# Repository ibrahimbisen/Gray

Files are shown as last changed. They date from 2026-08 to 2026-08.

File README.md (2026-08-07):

# Gray

**A 12-DOF quadruped robot.** Two students designed it, printed it, and built it.
The software teaches it to walk with reinforcement learning.

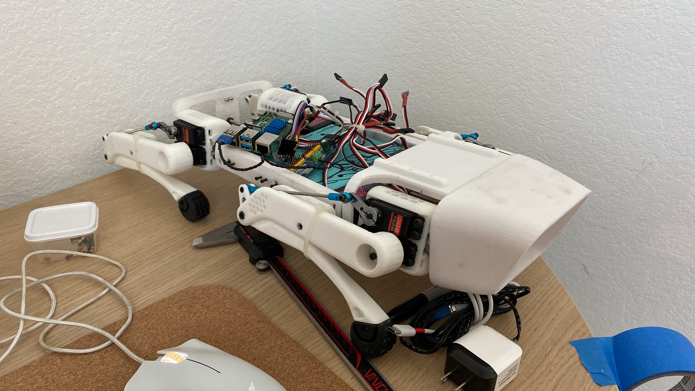
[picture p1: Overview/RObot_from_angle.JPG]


The robot is built. The parts are apart on a shelf. The work now is in simulation:
teach it to walk, teach it to stand up, then put the policy on the real machine.

---

## What it can do today

Every number below is measured in simulation, on 64 robots, over 25 seconds.
Nothing here is an estimate.

| | measured | it must reach |
|---|---|---|
| Walks forward | 6.7 m | 5.0 m |
| Top speed | 0.72 m/s — 2.6 km/h | — |
| Holds a straight line | 4.5° off | 7° |
| Turns on the spot | within 0.23 rad/s | 0.45 rad/s |
| Stays upright | 100 of 100 attempts | 90 |
| Climbs a 10° slope | 98 of 100 stay up | — |
| **Criteria passed** | **10 of 11** | 11 |

The one criterion left is the sideways walk. It misses by 3 mm/s.

Two policies made this table. The flat policy holds the line and the speed. A second
policy, trained on hills, does the climb. Hills and a straight walk pull against each
other: train on slopes and the line costs about 1.7° more. One policy for both is the
next decision, not a finished result.

---

## The robot

| | |
|---|---|
| Joints | 12 — three per leg |
| Servos | 12 × DS3218MG, 1.96 N·m, 270° |
| Mass | 3.1 kg |
| Sensors | 3 IMUs on the trunk, a potentiometer on every joint |
| Computer | Raspberry Pi, with an external ADC for the potentiometers |

**Three hardware facts change how the software must work.**

- The knee is a pushrod linkage. The servo angle is **not** the joint angle. A linear
  potentiometer on the rod measures the true knee angle.
- The servos take PWM at 50 Hz. That is the control ceiling. Feedback changes what the
  robot can sense, not how fast it can move.
- Only four servos sit in the body. Eight sit in the hip modules. The thigh and the calf
  hold no servo at all. This sets how heavy a leg is to swing.

---

## How to run it

Start two processes, in two terminals. Each one continues if you close the other.

```
python run.py              the training centre, at http://127.0.0.1:8000
python run.py --runner     works through the queue, unattended
```

Put jobs in the queue from the dashboard. The runner does them, one at a time.
Each job is **train**, then **verify**, then **film**.

Two training processes on one graphics card stop each other. So the runner takes one
job at a time, and that rule is structural rather than something to remember.

> ### Caution
> **Do not open a simulator window while a run trains.** A second process on the same
> card once stopped the machine and lost the run. This includes `Playground/pilot.py`,
> `scripts/drive.py`, and `find_stance.py --render`.
> The dashboard is safe. It uses the CPU only.

### Other commands

| | |
|---|---|
| `python run.py --check` | what the dashboard can see, then exit |
| `python scripts/train.py Gray-Walk --iterations 3000` | train one policy by hand |
| `python scripts/verify.py Gray-Walk` | score a policy against its criteria |
| `python scripts/scale_test.py` | how many robots this card can hold |
| `python Playground/pilot.py --run <run> --playground` | drive a trained policy yourself |
| `python tools/prepare_model.py "sim/URDF and Meshes V2"` | rebuild the model from CAD |

The three tasks are `Gray-Stand`, `Gray-Push` and `Gray-Walk`.

---

## Where to read more

| | |
|---|---|
| [PLAN.md](PLAN.md) | the stages, and the number each stage must reach |
| [RULES.md](RULES.md) | the decisions that hold across the project, and why |
| [CLAUDE.md](CLAUDE.md) | the hardware facts that do not change |
| [docs/REWARDS.md](docs/REWARDS.md) | what each reward term pays for |
| [Playground/README.md](Playground/README.md) | how to drive a policy by hand |

The dashboard holds more than these files do. It reads the live code, so it cannot
disagree with what the robot actually trained on.

---

## The machine

**The CAD model, and the URDF the simulation reads.**

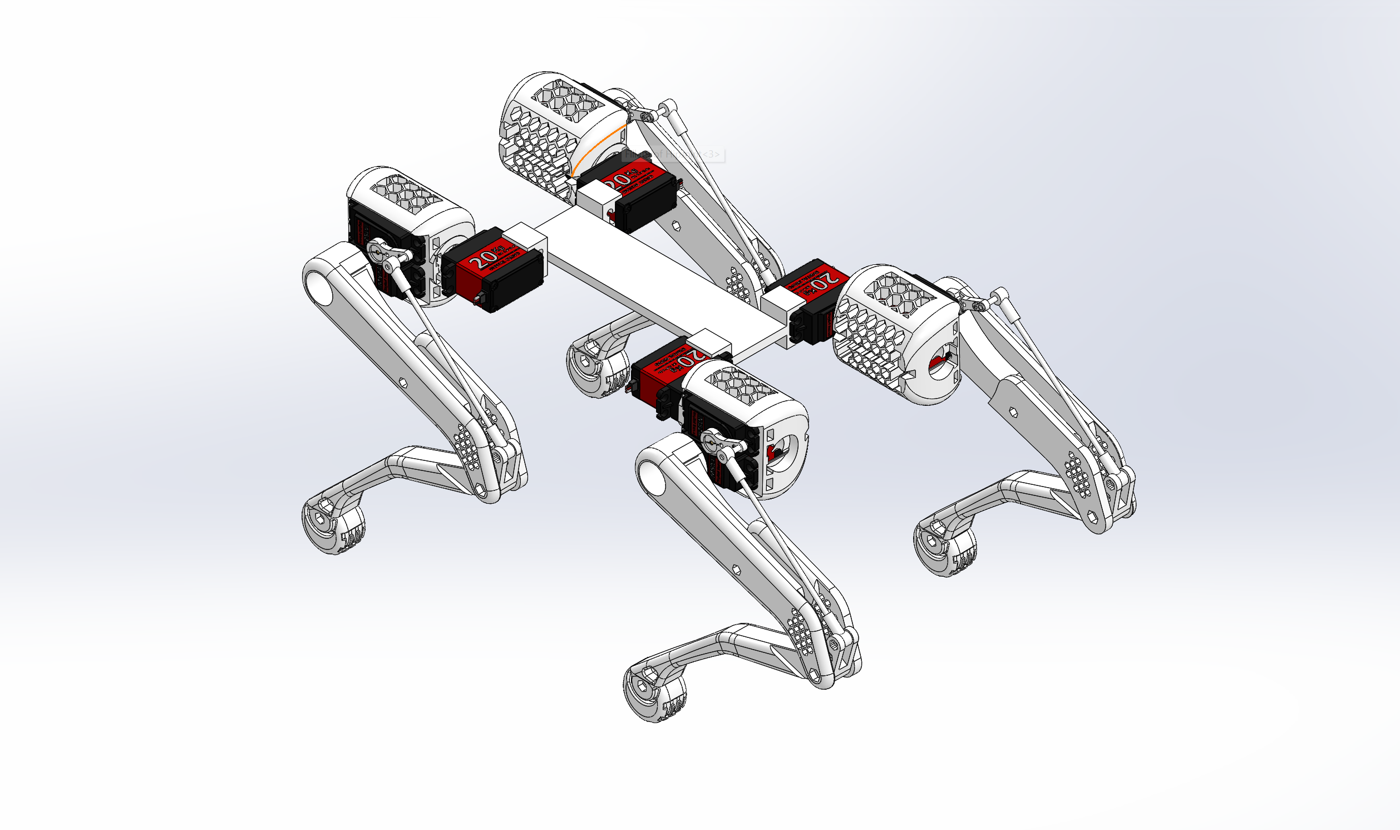
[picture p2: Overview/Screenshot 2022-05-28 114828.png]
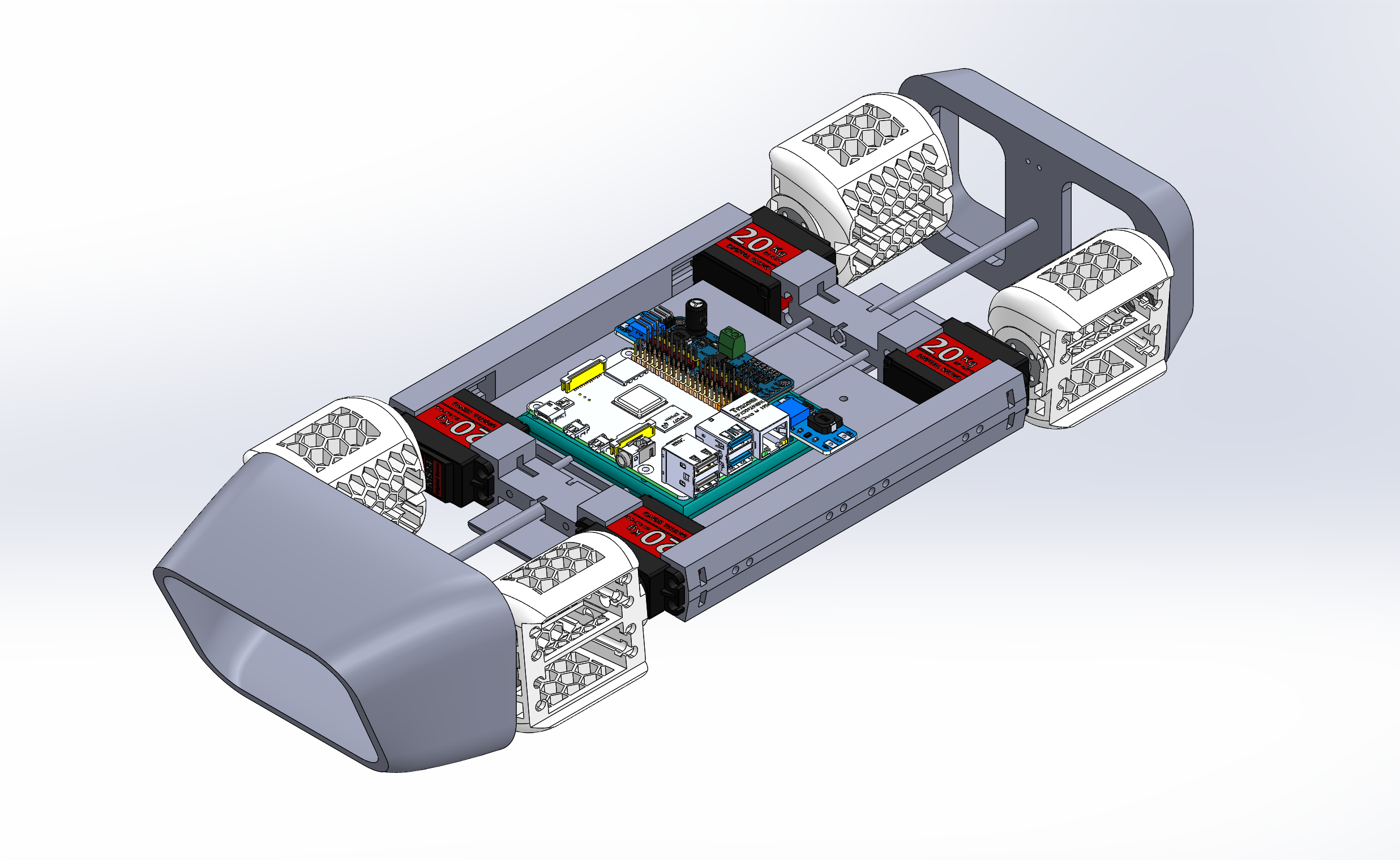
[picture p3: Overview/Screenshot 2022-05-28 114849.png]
 

**The build.** The controller, the legs, and the body with its electronics.

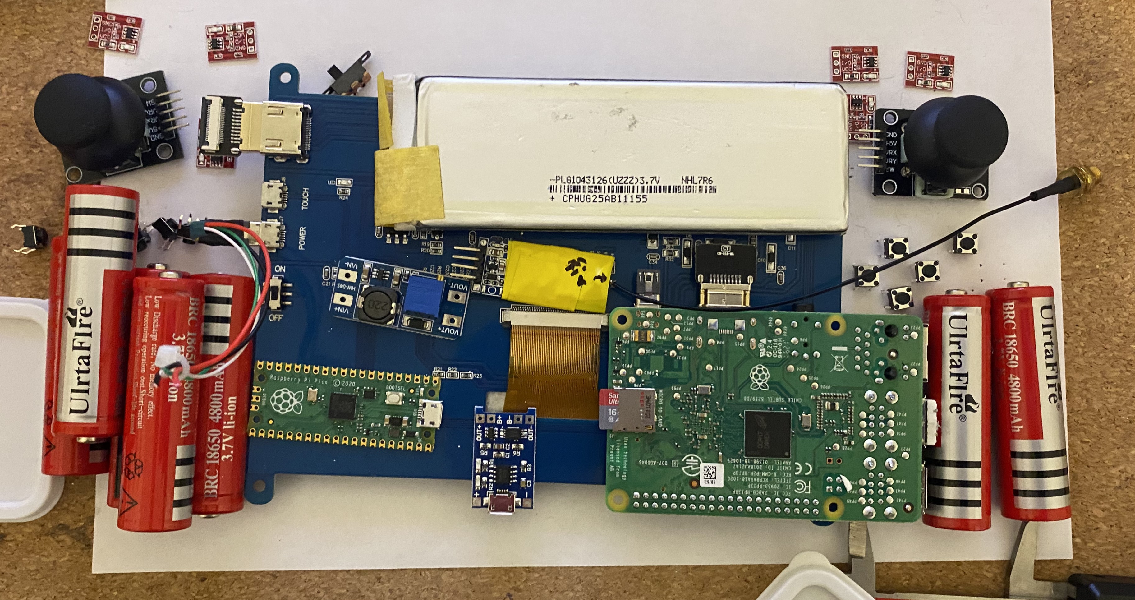
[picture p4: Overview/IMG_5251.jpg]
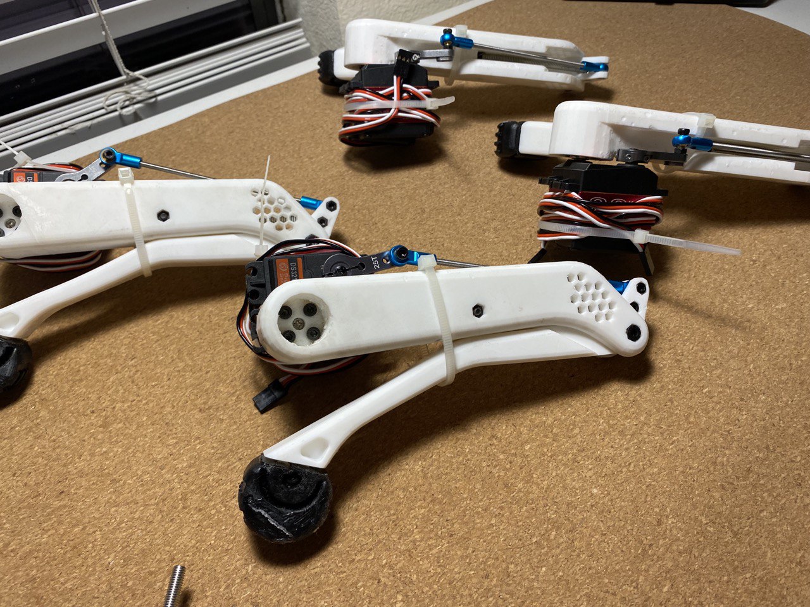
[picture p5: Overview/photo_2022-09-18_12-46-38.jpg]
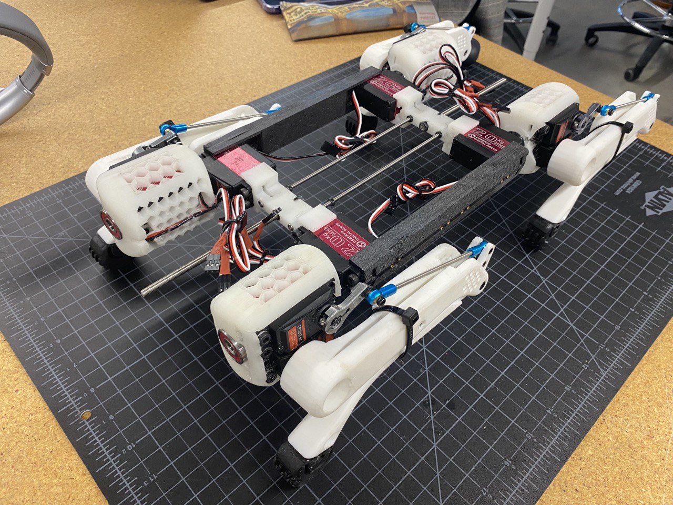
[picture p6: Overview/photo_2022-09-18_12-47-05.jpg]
  

**The first walk tests on the real robot.**



**In simulation.** Run 182, the most recent walk run, at three points in its training.
Each clip is 8 seconds. A pinned command drives the robot forward at 0.49 m/s, which is
70 percent of its 0.7 m/s top command. The camera trails the robot, so the ground shows
the distance covered.

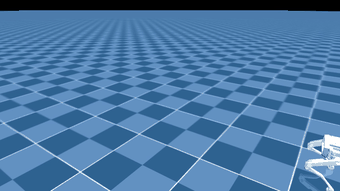
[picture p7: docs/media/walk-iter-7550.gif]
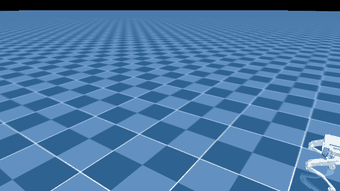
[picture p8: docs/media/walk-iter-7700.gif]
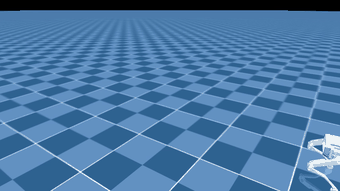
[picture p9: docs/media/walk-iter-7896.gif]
  

Run 182 tests a penalty that holds the hips near their home angle. It did not pass the
walk criteria, so these clips show the newest policy, not the best one. Over 8 robots it
covers 2.2 to 3.3 m in the 8 seconds, and none of them fall. The table at the top of this
page comes from two other policies.

**The earlier attempt**, at three points in its training. This software stack used a bad
CAD export, and the git tag `archive/attempt-1` holds it. The robot in these clips is the
old model.

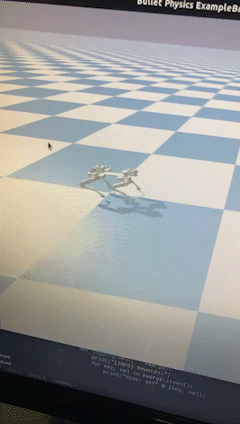
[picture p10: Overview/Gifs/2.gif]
  

---

## Contributors

- Ibrahim Eren Bisen
- Emin Alp Arslan

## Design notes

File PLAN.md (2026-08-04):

# PLAN.md — stage 2, train

Agreed 3 Aug 2026. This replaces the nine-subsection structure the dashboard
used to show.

**Where we are: 1.1.2 — and 1.2 has already happened.**

**Changed 3 Aug 2026, after 1.1.1.** 1.2 was going to come after 1.1, on the
grounds that you cannot tell whether a wider box broke something if the narrow
box was already broken. That was right while the plan was "tune the reward now,
widen later". It stopped being right the moment the decision was made to widen
*and* to add height, pitch and roll — because both throw every trained policy
away, so tuning the reward first would have meant tuning it twice.

So 1.2.1 to 1.2.3 are done, and **1.1 and 1.2.4 are now the same work**: the
rounds below tune the reward directly on the final box rather than on a box that
was about to be replaced. What that costs is the thing 1.2 was ordered after 1.1
to avoid — a harder debugging job if drift is still wrong. What it buys is not
paying for 25 hours of GPU twice.

---

## The shape

One pattern, applied twice.

    train it  ->  harden it  ->  measure it

Locomotion first, then getting up. Then join them. Then the sensors, twice: once
to keep what you had, once to use them.

**Every step ends on a number, not a date.** Nobody knows how long a reward
takes to get right — that is what the gates are for.

**Two things get tuned and they fight each other.** The REWARD says what good
means. The RANGE says where it has to be good. Widening the range makes the same
reward harder to satisfy, so they cannot be finished one after the other. That
is why the range stays pinned at its narrowest until 1.1 passes: you cannot tell
whether a wider range broke something if the narrow one was already broken.

---

## 1. Locomotion

### 1.1 Make it walk

- **1.1.1** Fix `wandering` to measure the line it was sent along — **done, 3 Aug**
- **1.1.2** Round 0 — noise floor. 3 seeds, one config
- **1.1.3** Round 1 — straightness factorial. 8 runs
- **1.1.4** Round 2 — speed terms. 4 runs
- **1.1.5** Round 3 — the winner, long, on unseen seeds. 3 runs
- **1.1.6** Add handover-shaped resets to R1's mix — *preparation for step 3*

> **Gate:** all six R1 criteria pass. Currently 4 of 6 — sideways drift is 21×
> its bar and speed tracking is 1.4× its bar.

Round 0 looks like the least and matters the most. Three identical configs on
three seeds; whatever they disagree by is the noise floor, and every later
difference has to beat it before it means anything.

### 1.2 The whole command box

- **1.2.1** Fix `_going_straight` to gate on `abs(vx)` — **done, 3 Aug**
- **1.2.2** Widen `WALK_SPEED` through zero to negative — **done, 3 Aug.**
  `(-0.35, 0.35)`. `WALK_SIDE` to `±0.20`, `WALK_TURN` to `±1.00`
- **1.2.3** Let `vy` be sampled without `vx` — **done, 3 Aug**
- **1.2.4** Retune — **this is now what 1.1's rounds do**
- **1.2.5** Add height, pitch and roll to the command — **done, 3 Aug.**
  Observation 45 → 48. Ranges measured, not chosen: height 0.15–0.25 m, pitch
  15° up to 8° down, roll ±20°, all inside where `find_stance` says the legs
  run out
- **1.2.6** Make the backward bar bite. **Not done.** `verify.py` carries
  `test_speed_back: -0.35` and reads it nowhere — the walk test still runs one
  pass, forward. Until it runs two and scores the worse, a run can be marked
  passed on forward alone. `drive.py --cases "-0.35,0,0"` measures it by hand
  in the meantime

> **A third thing was found here, and it was not in the plan.** mjlab's
> `rel_forward_envs` — set to 0.8 — did `.abs().clamp(min=0.3)` on the forward
> speed. On the old box that meant four attempts in five were forced to at least
> 0.3 m/s, three quarters of them landing exactly on it: the policy never trained
> across 0.15–0.35 at all. It trained at one speed. That is a live candidate for
> why speed tracking has been failing at 0.071 against a 0.05 bar. The `abs()`
> would also have flipped every backward command positive, so widening the range
> would have bought nothing. Replaced by `gray/tasks/walk_command.py`.

> **Gate:** the same six criteria, across the full range.

Measured on run #25: backward walked 0.00 m in 8 seconds, and pure sideways
walked 3 cm. Neither was ever sampled — `WALK_SPEED` is `(0.15, 0.35)`, so `vx`
is never zero and never negative. Four library rows filed as commands are not.

**1.2.1 must come first.** Widening the range without it trains backward walking
with no straightness penalty at all.

### 1.2b Steer it toward a crawl, not a trot — **owner's call, 4 Aug 2026**

The policy currently trots: diagonal pairs, front-right with back-left, lifting
together. Confirmed by watching run 34's films.

A trot is two feet down and the body falling between steps, caught by the servos
twice per stride. A crawl is one foot up and three always planted, so the weight
never leaves the triangle they make and nothing has to be caught.

In simulation the trot is fine — better, even. On the real robot it asks
DS3218MGs at 50 Hz, with backlash nobody has measured, to arrest a falling 3.1 kg
body twice a stride. **The owner's judgement is that they will not.** He built the
robot; that call is his and it is the right way round to be wrong.

So this is a sim-to-real decision made *before* the evidence rather than after,
which is unusual here and deliberate: finding out in stage 3.3 means every policy
trained until then is trained toward a gait the hardware cannot run.

**Not yet designed.** The honest options are a duty-factor term paying for three
feet down, a contact-schedule reward, or simply a much lower top speed — a trot
is partly what you get for asking for speed. Which one, and what it costs the
other bars, is the first thing to work out. It is NOT a weight change to
`stepping`: that term is already earning the maximum a trot can give it.

---

### 1.3 Turn the dials up

- **1.3.1** Widen what is already on — friction, mass, centre of mass, servo
  gains, joint friction
- **1.3.2** Terrain — slopes first, then uneven ground
- **1.3.3** Payload — to +2 kg, off-centre
- **1.3.4** Degraded hardware — weak servo, dead servo, low battery

> **Gate:** the same six criteria, dials at full.

The dials are not off. Foot friction is randomised 0.4 to 1.2 on every attempt
right now, along with ±20% mass, ±15 mm centre of mass and ±30% servo stiffness.
This step turns them up, it does not switch them on.

None of it is a new skill. The policy never sees the word gravel — it sees the
same 45 numbers in a different pattern. This is also where sim-to-real
robustness comes from: a policy that survives the range survives the real value,
which is the correct answer to three numbers nobody can measure yet.

### 1.4 Measure

- **1.4.1** Top speed, and the speed ladder
- **1.4.2** Acceleration, sustained run
- **1.4.3** Smoothness, read off the trained policy

> **No gate.** Numbers written down, nothing trained.

"Find top speed" has no reward term. You raise the command until it fails and
write down where. The trained half of smoothness — `twitching`, `rocking`,
`shaking`, `joint_shock`, `landing_speed` — is already ramping in during 1.1.

---

## 2. Getting up

### 2.1 Make it stand up

- **2.1.1** Write the recover task — start poses, reward, terminations
- **2.1.2** Reward it for **ending where R1 starts** — stable, at ride height,
  low joint velocity — *preparation for step 3*
- **2.1.3** Train it

> **Gate:** up from 9 of 10 random ground poses, in under 3 s.

The one group that genuinely needs its own policy file. There is no commanded
velocity to track when the robot is on its back, so `track_speed`, `stepping`,
`dragging` and `wandering` are all meaningless.

### 2.2 Turn the dials up

- **2.2.1** The same dials as 1.3, applied to R2

> **Gate:** still 9 of 10, dials at full.

### 2.3 Measure

- **2.3.1** Time to stand, per start pose

> **No gate.**

---

## 3. Join them up

- **3.1** The switch rule — hysteresis and a settle time, so control cannot
  chatter at the boundary
- **3.2** The test — 100 drops: R2 stands it up, hands over, R1 walks 5 m

> **Gate:** 100 handovers with no stall and no fall-loop.

**The failure this prevents.** R2 finishes and says "upright, take it." R1
receives a robot mid-wobble, with joint velocities and a trunk height it has
never seen, because R1's resets always start it clean:

    nudge_base:  x, y ±0.01 m,  yaw ±0.1 rad,  velocity_range {}
    joint reset: velocity ±0.05 rad/s

That is a robot standing still. R1 has trained on nothing else. Hand it an
out-of-distribution state and it falls; R2 picks it up, hands over, it falls
again. No runtime rule fixes that loop.

**Which is why 1.1.6 and 2.1.2 exist.** The preparation happens during training,
in the two steps above. Only the switch rule and the test are genuinely here. Skip
the preparation and this step is where you find out.

---

## 4. Sensors — keep what you had

- **4.1** Fit them. CAD positions needed for the three where the mounting is in
  the maths
- **4.2** Model each one in the simulator, including how it fails
- **4.3** Warm-start — grow the network, copy the old weights across, initialise
  the new input columns to **zero** so day one behaves identically to the best
  policy
- **4.4** Retrain R1 and R2 from that warm start

> **Gate:** every bar that passed before still passes, with 95 inputs.

Ten sensors decided; seven add inputs. 45 → 95 numbers, which is why they go in
as one batch: each one alone costs the same full retrain as all of them
together.

The three where mounting position is a coefficient rather than documentation:
the five optical flow units (each reads `v + ω × r`), the middle IMU (offset
from the centre of mass), and the six range finders (origin and aim vector, which
the simulator turns into raycasts).

**This gate is a regression check.** It proves nothing broke. It does not say
the sensors were worth fitting — that is step 5.

---

## 5. Sensors — use them

- **5.1** Tighten the bars. They were set for a blind policy
- **5.2** Write reward terms that were impossible before:
  - **slip** — five flow units against the IMU's yaw rate. Nothing else on the
    robot can see a slip
  - **landing** — load cells turn "did it slam" from a guess into a number
  - **anticipation** — range finders make stepping over something before
    touching it reachable at all
- **5.3** Retune against the tighter bars

> **Gate:** numbers that were out of reach before now pass.

The policy currently cannot measure its own speed — `base_lin_vel` sits in the
critic group, which is thrown away after training, precisely because the real
robot has no way to measure it. So it infers its speed while `track_speed`, its
largest reward term, scores exactly that. Optical flow measures it directly.

5.2 also unblocks library rows. Some of the rows filed under "needs a camera"
are reachable with range finders instead, which is the cheap half of seeing.

---

## Shelved

| | Trigger to un-shelve |
|---|---|
| **R3** — using a foot on an object | None. Nothing depends on it, and it needs objects in the scene nothing else does. |
| **Jumping** | Stage 3.3 measures the real servo **speed** under load. Torque is not the blocker — higher-torque hobby servos are usually slower. |
| **Seeing** | A camera the *policy* reads, plus a heightmap pipeline and the worst sim-to-real gap on the list. Not the camera used to drive the robot. |
| **The real robot** | Deferred by choice, not blocked by anything. |

**On the last one.** Stage 3.3 measures three numbers the model is guessing —
servo gains, backlash, loop latency. Every policy trained before it is trained
against those guesses. One policy depends on them today. After steps 1 to 5,
two do, hardened and tuned against a robot that may not be the real one.

That is the cost of deferring it. It is a real cost and it is the owner's call.

---

## Rules while this runs

- One training process on the card at a time. RULES.md rule 4.
- Every run is verified when it finishes. A run nobody scored is a run that did
  not happen.
- Nothing in `gray/tasks/` changes while a round is in flight. A weight edited
  mid-round makes every run before it unreadable.
- Films stay on. About 4% of throughput at one clip per 100 iterations, and the
  only way to see a robot doing something the numbers do not describe.

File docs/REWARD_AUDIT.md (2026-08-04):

# Reward audit — 3 Aug 2026

Every scoring term in the live walk task, checked against the published work. Seven
findings, ranked by how likely each is to be costing something right now. Everything
checked and found sound is recorded at the bottom, because a term that was examined and
cleared is worth knowing about too.

The config audited is the one `progress/runs/2026-08-03_14-42-29_walk_m3100_d/run.json`
was written from: **24 scoring terms** — 9 that pay, 15 that charge — with a ceiling of
9.5 per second, 190 over a 20 s episode.

**One arithmetic fact that everything below depends on.** mjlab computes
`reward = raw × weight × dt` with `dt = 0.02 s`
([reward_manager.py:116](../.venv/Lib/site-packages/mjlab/managers/reward_manager.py#L116)).
A term that fires every step accumulates 50 times per second. A term that fires **once**
— falling over — is multiplied by 0.02 and never repeats. Those two are not on the same
scale, and finding 5 is entirely about that.

---

## 1. `ground_covered` pays nothing for walking backward, and full marks for drifting while told to stand

**What the code does.** [walk_env_cfg.py:414-436](../gray/tasks/walk_env_cfg.py#L414-L436).
It measures displacement along **world X**, divides by the distance asked for, and clamps
the result to `[0, 1]`.

**Failure A — backward.** A backward command produces negative world-X displacement.
`clamp(negative, 0, 1)` is 0. A robot walking backward perfectly earns exactly the same
from this term as one that does not move at all: nothing.

How much of the command box that is:

| share of envs | command | `ground_covered` earns |
|---|---|---|
| 15% | standing (zeroed in `_update_command`) | see failure B |
| ~21% | straight, `vx ∈ [-0.35, -0.10]` | **0** |
| ~21% | straight, `vx ∈ [+0.10, +0.35]` | works |
| ~43% | general draw, half of which has `vx < 0` | **0** for about half |

Roughly **40% of all environments cannot earn this term at all.** They can only lose the
1.0 it is worth.

**Failure B — standing.** For a standing env `asked = 0`, and the code guards with
`clamp(asked, min=1e-6)`. So `progress / 1e-6` — any forward drift at all, a micron of
it — saturates the clamp and pays the **full 1.0**. A robot told to stand still is paid
maximum for creeping forward.

**Failure C — turning.** World X is not the commanded direction once the robot has turned.
The term drifts out of alignment with the command over an episode.

**Why this matters beyond the term itself.** `gray_skill_library.csv` row 8 — "Walk
backward, sideways and diagonally" — is filed `blocked_on: range`, with the note that run
25 covered 0.00 m backward in 8 s. The command box was widened through zero on 3 Aug 2026
to fix that. This term was not changed in the same edit, so widening the box alone will
not unblock row 8: the robot is now *asked* to go backward and still *paid* nothing
for doing it.

This is the same shape as the `_going_straight` positive-only trap that was caught in that
change ([walk_env_cfg.py:368](../gray/tasks/walk_env_cfg.py#L368)). That one was fixed.
This one was next to it and was missed.

**Fix.** Project displacement onto the commanded direction instead of onto world X, and
gate the term off below `MOVING` so the standing case cannot pay:

```
want = command[:, :2] / ||command[:, :2]||        # unit vector, body frame
progress = (pos_t - pos_{t-1}) · want              # signed, along the command
return clamp(progress / (||command[:, :2]|| · dt), 0, 1) * (||cmd|| > MOVING)
```

That is the same rotation `wandering` already does at
[walk_env_cfg.py:551](../gray/tasks/walk_env_cfg.py#L551).

---

## 2. `stepping` is not command-gated, so marching in place beats standing still

**What the code does.** [walk_env_cfg.py:269-277](../gray/tasks/walk_env_cfg.py#L269-L277).
Fraction of the four feet whose air time is between 0.10 s and 0.45 s. Weight 1.0. It
carries no command gate.

**The conflict.** 15% of environments are commanded to stand
(`rel_standing_envs=0.15`). For those:

- feet planted → all air times 0 → `stepping = 0`
- marching on the spot → up to `stepping = 1.0`

And nothing charges for the marching, because every gait *penalty* **is** gated on
`MOVING`: `dragging`, `swing_height` and `hard_landing` all multiply by
`moving.float()`, and `leg_swing` gates the same way. Only `skidding`, `landing_speed`,
`joint_shock`, `shaking` and `effort` push back, and together they are worth a fraction of
1.0.

So for one environment in seven the reward strictly prefers marching in place to standing
still. `track_speed` does not object — a robot marching without translating still scores
~1.0 on it.

legged_gym ships a `stand_still` reward whose entire job is the opposite of this. Gray has
neither the gate nor the counter-term.

**Fix.** Gate `stepping` on `MOVING`, the same way `leg_swing` already is. One line.

---

## 3. Three explicit gait priors, no energy term — the 2026 result says that is backwards

Gray pays for gait shape three separate ways: `stepping` (air time), `leg_swing` (joint
excursion), `swing_height` (peak height). It has **no** power or energy term anywhere in
any of the three tasks.

LoComposition ([arXiv:2606.15896](https://arxiv.org/abs/2606.15896)) tested exactly this
trade and found it the wrong way round:

- Their whole reward is **two things**: velocity tracking, and a mechanical-power penalty
  `λ_E · Σ|τ_j q̇_j|` ramped in and saturating at 0.008.
- Gait priors — they name **air time and contact counts specifically** — "reduce terrain
  traversability and prevent lower-CoT solutions". The variants *with* priors performed
  **worse**.
- Without the power term the policy "settles on an energetically expensive bounding gait".
  With it, trotting appears on its own, at **56% lower cost of transport**.

Their framing is the useful part: energy is not a tidiness penalty, it is *the signal that
picks the gait* out of the feasible set. Gray currently picks the gait by hand, with three
terms, and then has nothing selecting for efficiency.

This matters more here than on their robot, not less. Gray's binding hardware constraint
is 1.96 N·m servos with no torque limiting and no overheat protection. `effort`
(`joint_torques_l2`, −0.0002) prices torque but not *power* — a joint holding a heavy
static load and a joint doing real work look the same to it.

`electrical_power_cost` already exists in mjlab
(`mjlab.envs.mdp.rewards.electrical_power_cost`, `sum(clamp(τ·q̇, min=0))`) and
`REWARDS.md` already lists it for stages 5 and 8. It is simply not in the config.

**Suggestion, not a fix.** Add `electrical_power_cost`, ramped in the way the other
tidiness terms already are, starting near zero. Then try dropping `stepping` and see
whether the gait survives. That is a cheap experiment and it is the one the paper says
pays.

---

## 4. 24 terms is past where the literature says hand-tuning stops working

Term counts, like for like:

| | terms | note |
|---|---|---|
| LoComposition (2026) | **2** | tracking + power |
| Kim et al. (2023) | **3** rewards + 11 constraints | tracking, torque, smoothness |
| Digit standing/walking (2024) | **14** | described as "minimally constraining" |
| legged_gym / Isaac Lab defaults | 10–12 | |
| **Gray walk** | **24** | 9 pay, 15 charge |

Kim et al. ([arXiv:2308.12517](https://arxiv.org/abs/2308.12517)) state the problem
directly: *"Finding the relative weights for each of the reward terms based on the
resulting robot's motion is not trivial because there are often more than ten reward
terms"*, and that this tuning *"often takes several months"*. Their answer is to move the
regularisation terms out of the reward and into hard constraints with physically meaningful
thresholds — joint limits, contact, foot clearance — leaving three coefficients to tune.
Eleven of their twelve constraint thresholds can be read straight out of the robot
description file rather than tuned at all.

Gray's terms cluster into groups that price overlapping things:

- **"move"** — `track_speed` 2.0, `ground_covered` 1.0, `leg_swing` 1.0, `stepping` 1.0
- **"trunk steady"** — `upright` 1.0, `rocking` →−0.2, `shaking` →−0.01
- **"hold a line"** — `track_turn` 1.0, `veering` →−2.0, `wandering` −1.0
- **"smooth"** — `twitching` →−0.05, `jitter` −0.01, `joint_shock` −2.5e-7
- **"feet"** — `dragging` −2.0, `skidding` −0.5, `swing_height` −0.25,
  `landing_speed` →−0.8, `hard_landing` −1e-4

Overlap is not automatically wrong, and the code argues each pair catches a distinct
failure — that argument is generally sound and in two cases (`veering` vs `wandering`,
`twitching` vs `jitter`) it is demonstrably right, because both were found the hard way.
But five clusters of three to five terms each is where the cited failure lives, and Gray
has no mechanism for noticing when two of them start fighting other than a run going
wrong.

**Not a recommendation to cut terms blindly.** It is a recommendation to log the
per-term contribution and see which of the 24 are actually earning. `metrics.csv`
currently carries 5 of the 24 reward terms. rsl_rl already writes `Episode_Reward/*` for
every one of them to tensorboard; `WATCH` in [scripts/train.py:115](../scripts/train.py#L115)
just doesn't forward them. Widening `WATCH` is the cheapest useful thing on this list.

---

## 5. `fell_over` at −40 is worth about 5% of what falling actually costs

This is the non-obvious one, and it is pure `dt` arithmetic.

`is_terminated` fires **once**. Its contribution is `1 × −40 × 0.02 = −0.8`.

What falling actually costs is the reward that stops arriving. At convergence run `_d`
scores 137.4 per 20 s episode, so the per-step reward is `137.4 / 20 = 6.87` before dt, or
0.137 after. With `gamma = 0.99` the value of carrying on is

```
0.137 / (1 − 0.99) ≈ 13.7
```

So falling costs about **14.5**, of which the termination penalty is **0.8 — 5.5%**.

Two consequences:

- Raising `fell_over` from −20 to −40 in the push task changed the cost of falling by
  about 2.7%. It very likely did nothing. If falling needs to cost more, the lever is
  `gamma` or the ongoing reward, not this weight.
- Early in training the ratio is different. At iteration 0 the per-step reward is
  `0.589 / (19.18 × 0.02) ≈ 1.54` before dt, so continuation is worth ~3.1 and the
  penalty is ~21% of the cost. The term does real work at the start and almost none at
  the end, which is the opposite of how it reads.

Claas Voelcker's write-up of the sign/termination interaction states the general rule:
under negative rewards termination is a *reward* to the agent, under positive rewards it
is a punishment, and mixing them makes the behaviour hard to predict. Gray mixes them —
`alive` +0.5 and `fell_over` −40 — which is normal practice, but it means the two have to
be read together and neither number means much alone.

---

## 6. mjlab does not clip the summed reward at zero. legged_gym does

`RewardManager.compute()`
([reward_manager.py:116-133](../.venv/Lib/site-packages/mjlab/managers/reward_manager.py#L116-L133))
sums the weighted terms and returns them. There is no `clip(min=0)`. legged_gym has
`only_positive_rewards`, and its own comment says the clip *"avoids early termination
problems"* — under a net-negative step reward, ending the episode beats carrying on, and
the agent learns to fall on purpose.

**Checked: not currently happening.** Mean step reward is positive at iteration 0 (≈1.54)
and at convergence (≈6.87), on a 9.5 ceiling.

**But the margin shrinks by design.** The curriculum
([walk_env_cfg.py:737-750](../gray/tasks/walk_env_cfg.py#L737-L750)) raises `veering`
−0.2 → −2.0, `landing_speed` −0.1 → −0.8, `rocking` −0.02 → −0.2, `shaking` −0.001 →
−0.01 and `twitching` −0.01 → −0.05 across the first 12,000 steps. That is the one time
this could bite: a policy that has *not* learned to hold a line by iteration 500 gets
`veering` at −2.0. `veering` returns `wrap_to_pi(...)²`, which is bounded — but at π²,
so at −2.0 a robot 90° off its line pays 4.9 per step against a 9.5 ceiling, and a robot
facing backwards pays **19.7, more than twice everything the reward can pay it.**
`wandering` is worse: `clamp(off − 0.05, min=0)` has no upper bound at all and grows with
distance.

**Suggestion.** Cap both. Every other term in the file is bounded — six exponentials, two
clamps, a binary — and `RULES.md` rule 1's stop threshold is defined against a ceiling
that only the positive side actually respects.

---

## 7. `landing_speed` has no plain-English note, and `train.py` warns instead of refusing

`run.json` for the live run ships `"name": "landing_speed", "what": ""` — a blank row on
the dashboard, which the code's own comment calls *"worse than no row"*.

The cause: `landing_speed` was added at
[walk_env_cfg.py:720](../gray/tasks/walk_env_cfg.py#L720) but never added to `WALK_NOTES`.

`CLAUDE.md` says *"train.py refuses to start if one is missing"*. It does not —
[scripts/train.py:386-390](../scripts/train.py#L386-L390) prints `[warn]` and carries on.
The rule that was supposed to enforce itself printed one line into a training log and was
never seen.

**Fix.** Add the note, and make the check `raise` so the documented behaviour and the
actual behaviour agree.

---

## Checked and found sound

- **The tracking band, σ = 0.15.** Correct, and the reasoning behind it holds. The
  standing-still exploit it was written to kill is genuinely dead: at a commanded
  0.25 m/s a stationary robot now scores 0.06 instead of 0.78. Re-checked against the
  *widened* box: the only residual is envs drawn with a very small non-zero command
  (~6% of envs, worth ≤0.9 instead of 1.0), which is negligible and points the right way
  anyway. **Do not change this number.**
- **The turning band, TURN_STD = 0.80.** The reasoning in the file — set the band against
  the error the robot *makes*, not the command it is *given* — is a genuinely good
  generalisation and I did not find it stated this clearly in any of the papers.
- **The reward ceiling of 9.5 is real.** Every one of the nine positive terms genuinely
  caps at 1.0: six are `exp(−·)`, `ground_covered` and `leg_swing` are clamped, `stepping`
  is divided by 4, `alive` is binary. `RULES.md` rule 1 is safe on the positive side.
  (The negative side is finding 6.)
- **Ramping the tidiness penalties.** Matches RMA and matches this project's own `push_v3`
  failure. LoComposition ramps its power penalty the same way. Correct.
- **Exponential kernels on tracking terms.** The survey
  ([arXiv:2406.01152](https://arxiv.org/abs/2406.01152)) recommends bounded functions —
  clipping or exponential kernels — for stable training. Gray does this throughout.
- **`end_stops` −5.0 and `fell_over` −40.** Not stale inherited values; both were
  deliberately re-weighted in [push_env_cfg.py:194-204](../gray/tasks/push_env_cfg.py#L194-L204)
  with the knee-travel reasoning written out. (`fell_over` is finding 5 for a different
  reason.)
- **`jitter` (second difference) instead of a bigger `action_rate`.** This is the right
  call and the literature agrees: Kim et al. use exactly this pair — first *and* second
  difference of the PD target — as their single smoothness reward.
- **Contact-sensor slip detection rather than a height threshold.**
  [push_env_cfg.py:65-77](../gray/tasks/push_env_cfg.py#L65-L77). Correct, and the
  reasoning given is the reason.
- **`effort` at −0.0002.** Unrevisited since the stand task, but it is A1's and Go2's own
  config value and `REWARDS.md` already justifies it. Leave it; finding 3's power term is
  the better lever.

---

## The one general lesson

Every finding above except 3 and 4 is the same failure in a different place: **a term
whose value is zero looks exactly like a term that is passing.** `ground_covered` returns
0 for backward commands. `_going_straight` returned False for backward commands.
`feet_air_time` returned 0 because a Go1 threshold was never reached. `track_turn` returned
1.4e-11 for three whole runs. A blank `what` string renders as an empty row.

None of these throw. None of them look wrong on a curve. The project has now been bitten
by this four separate times, and the countermeasure is the same each time: **log every
term's actual contribution and look for the ones sitting at zero.** That is the `WATCH`
change in finding 4, and it is worth more than any individual weight on this list.

---

## Sources added by this audit

Everything in `REWARDS.md`'s source list still stands. New:

- Kim et al., *Not Only Rewards But Also Constraints*, [arXiv:2308.12517](https://arxiv.org/abs/2308.12517) — 3 reward coefficients + 11 constraints; the "more than ten terms" problem stated outright
- van Marum et al., *Revisiting Reward Design and Evaluation for Robust Humanoid Standing and Walking*, [arXiv:2404.19173](https://arxiv.org/abs/2404.19173) — minimally constraining rewards; the standing-still bias stated directly; a hardware benchmark that does not depend on the reward
- *LoComposition*, [arXiv:2606.15896](https://arxiv.org/abs/2606.15896) — gait priors harm; mechanical power selects the gait; 56% lower CoT
- *Learning-based legged locomotion: state of the art and future perspectives*, [arXiv:2406.01152](https://arxiv.org/abs/2406.01152) — the taxonomy, and "there is no general set of rules one can follow"
- Chamorro, [legged-gym single-term ablation](https://wandb.ai/simonchamorro/legged-gym/reports/Legged-Locomotion-Environment-Experiments-in-Isaac-Gym--VmlldzoxODE2MDY0) — 9 terms removed one at a time; linear and angular velocity tracking dominate, everything else is marginal
- Voelcker, [Reward Design and Termination](https://cvoelcker.de/blog/2025/reward-functions/) — reward sign × termination × discount

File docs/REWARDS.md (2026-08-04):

# Reward functions — one reference for every stage

What Gray actually scores, per stage, with the real weights, next to what the established
implementations use. Compiled from the installed mjlab source, this project's own run
history, and the published work on legged_gym, Isaac Lab, Unitree, ANYmal,
Walk-These-Ways, MIT Cheetah, D²-GMBC and the hobby-servo quadrupeds.

Findings from checking this config against that literature live in
[REWARD_AUDIT.md](REWARD_AUDIT.md). This file is the reference; that one is the
argument.

**A units note that makes every number below comparable.** mjlab, legged_gym and
Isaac Lab all compute `reward = raw × weight × dt`. Gray runs at `dt = 0.02 s`
(50 Hz), the same convention, so config weights transfer between those three
directly. They do **not** transfer from numbers printed in papers, which sometimes
quote the already-dt-multiplied value or use a different formula entirely. Every
paper-sourced figure below says so.

**A second consequence of that same `dt`, which is easy to miss.** A term that fires
every step is multiplied by 0.02 fifty times a second. A term that fires **once** —
`fell_over` — is multiplied by 0.02 and then never again. They are not on the same
scale, and comparing their weights directly is wrong. See audit finding 5.

---

## 1. One reward function, not three

There is one reward set, built by inheritance:

```
stand_env_cfg.py    10 terms
      │  push_env_cfg.py adds shove + DR, adds 4 terms, re-weights 5
      ▼
push_env_cfg.py     14 terms
      │  walk_env_cfg.py drops 7, adds 17, re-weights 1
      ▼
walk_env_cfg.py     24 terms   ← the live one
```

That is the industry norm and not an accident. legged_gym, Isaac Lab and mjlab all use a
single reward set for locomotion; standing still is the zero-velocity command, not a
separate task. A genuinely separate reward is normal only for a genuinely separate task —
fall recovery is the standard example, and **Gray has not written one yet.** Stage 7
below is a plan, not a file.

---

## 2. The live walk set — all 24 terms

Weights from `progress/runs/2026-08-03_14-42-29_walk_m3100_d/run.json`, which
`scripts/train.py` writes from the live config. Terms marked **↗** are ramped by the
curriculum; the arrow shows start → end.

### Pays (9 terms, ceiling 9.5 / s)

| Term | Weight | What it measures | Where |
|---|---|---|---|
| `track_speed` | **2.0** | `exp(−‖cmd_xy − v̄_xy‖²/σ²)`, σ = 0.15, on a **12-step EMA** of trunk speed | ours, [walk_env_cfg.py:262](../gray/tasks/walk_env_cfg.py#L262) |
| `track_turn` | **1.0** | `exp(−(yaw err² + ‖ω_xy‖²)/σ²)`, σ = 0.80 | `vmdp.track_angular_velocity` |
| `ground_covered` | **1.0** | net world-X progress ÷ distance asked, clamped [0,1] | ours, [:414](../gray/tasks/walk_env_cfg.py#L414) — **see audit finding 1** |
| `upright` | **1.0** | `exp(−(pitch err² + roll err²)/σ²)`, σ = 0.45, vs the **posture command** | ours, [:398](../gray/tasks/walk_env_cfg.py#L398) |
| `ride_height` | **1.0** | `exp(−(z − cmd_z)²/σ²)`, σ = 0.05, vs the **posture command** | ours, [:384](../gray/tasks/walk_env_cfg.py#L384) |
| `posture` | **1.0** | joints near default, tolerance widening with commanded speed | `vmdp.variable_posture` |
| `stepping` | **1.0** | fraction of feet with air time in 0.10–0.45 s | ours, [:269](../gray/tasks/walk_env_cfg.py#L269) — **see audit finding 2** |
| `leg_swing` | **1.0** | mean thigh/calf excursion about a running average, capped at 0.15 rad | ours, [:439](../gray/tasks/walk_env_cfg.py#L439) |
| `alive` | **0.5** | per-step bonus while not terminated | `mdp.is_alive` |

Every one of these genuinely caps at 1.0 — six are `exp(−·)`, two are clamped, one is
binary — so the 9.5 ceiling `RULES.md` rule 1 depends on is real.

### Charges (15 terms)

| Term | Weight | What it measures | Where |
|---|---|---|---|
| `fell_over` | **−40** | termination penalty, fires once | `mdp.is_terminated` |
| `end_stops` | **−5.0** | soft joint-limit violation | `mdp.joint_pos_limits` |
| `dragging` | **−2.0** | `Σ ‖height − 0.035‖ × ‖v_xy‖` per foot, gated on MOVING | ours, [:286](../gray/tasks/walk_env_cfg.py#L286) |
| `veering` ↗ | **−0.2 → −2.0** | accumulated heading error off the commanded line, squared; caps at π² so **−19.7 at full ramp** | ours, [:482](../gray/tasks/walk_env_cfg.py#L482) |
| `wandering` | **−1.0** | cross-track displacement past 50 mm, **no upper bound** | ours, [:505](../gray/tasks/walk_env_cfg.py#L505) |
| `skidding` | **−0.5** | `Σ ‖v_xy‖²` per foot while in contact | `push_env_cfg.foot_slip` |
| `swing_height` | **−0.25** | `(peak/0.035 − 1)²`, charged at landing | ours, [:303](../gray/tasks/walk_env_cfg.py#L303) |
| `landing_speed` ↗ | **−0.1 → −0.8** | downward foot speed at the instant of touchdown | ours, [:333](../gray/tasks/walk_env_cfg.py#L333) |
| `rocking` ↗ | **−0.02 → −0.2** | `Σ ω_xy²` on the trunk only | `vmdp.body_angular_velocity_penalty` |
| `twitching` ↗ | **−0.01 → −0.05** | `Σ (aₜ − aₜ₋₁)²` | `mdp.action_rate_l2` |
| `jitter` | **−0.01** | `Σ (aₜ − 2aₜ₋₁ + aₜ₋₂)²` | `mdp.action_acc_l2` |
| `shaking` ↗ | **−0.001 → −0.01** | trunk's own linear acceleration, squared | ours, [:463](../gray/tasks/walk_env_cfg.py#L463) |
| `effort` | **−0.0002** | `Σ τ²` across the twelve joints | `mdp.joint_torques_l2` |
| `hard_landing` | **−1e-4** | contact force at touchdown | `vmdp.soft_landing` |
| `joint_shock` | **−2.5e-7** | `Σ q̈²` | `mdp.joint_acc_l2` |

Every term that pays is bounded at 1.0. `veering` and `wandering` are the only two that
charge without a useful bound, and `veering` is also the one that ramps hardest — at full
ramp it can charge more than twice the entire positive ceiling. Audit finding 6.

### The curriculum

Five terms ramp in over the first 12,000 env steps (≈ iteration 500), driven by
`vmdp.reward_curriculum` at [walk_env_cfg.py:737](../gray/tasks/walk_env_cfg.py#L737).
Steps 0 / 2400 / 6000 / 12000 land at roughly iteration 0, 100, 250 and 500.

This is not tidiness. RMA ramps its whole penalty vector from k=0.03 via
`k_{t+1} = k_t^0.997` because a fixed large penalty from step 0 makes the policy "learn to
stay in place because of the penalty terms". This project hit the same wall independently:
`push_v3` set `twitching` to −1.5 from step 0 and the robot stopped being able to catch
itself. LoComposition (2026) ramps its power penalty the same way. Three sources, one
lesson: **first learn to walk, then learn to walk neatly.**

### What walk drops, and why

| Dropped | Reason |
|---|---|
| `still` | it is being asked to move |
| `joint_speed` | same; legged_gym disables this for walking too |
| `foot_lift` | `stepping` and `swing_height` are the gait versions of it |
| `spinning` | it fined *all* trunk rotation including the commanded yaw — paying and fining the same motion |
| `tilt` | replaced by `upright`, the same measurement scored the way the walking references score it |
| `height`, fixed `posture` | replaced by the commanded-posture and variable-tolerance versions |

### The commands

Two command terms on the same 5–10 s clock, so one draw is one coherent instruction.

**`walk`** — `StraightLineVelocityCommandCfg`, `vx ∈ ±0.35`, `vy ∈ ±0.20`,
`ωz ∈ ±1.00`. 15% standing; 50% of the rest redrawn as a pure straight line, forwards
**or backwards**, with `|vx| ≥ 0.10`. The subclass exists because mjlab's
`rel_forward_envs` does `abs().clamp(min=0.3)`, which erases the sign — on the widened box
that would have flipped 80% of backward commands back to forward and the measurement
afterwards would have said backward still does not work.

**`posture`** — height 0.15–0.25 m, pitch −0.26 to +0.14 rad, roll ±0.35 rad, 25% at
nominal. This is what turns `upright` and `ride_height` from fixed targets into commands:
level and stance height are simply the command at zero, and a crouch or a lean becomes
something you can ask for instead of something the robot is punished for.

### The three numbers that were wrong and are now right

Worth keeping in this file because each cost runs to find.

1. **σ on `track_speed` = 0.15, not mjlab's 0.5.** At 0.5, a robot commanded 0.25 m/s and
   standing perfectly still collects `exp(−0.25²/0.5²) = 0.78` — 78% of full marks for
   doing nothing. At 0.15 it collects 0.06. IsaacLab issue #458 reports the same failure
   independently, and it is very likely what the archived attempt did.
2. **σ on `track_turn` = 0.80, not 0.30.** The same trap in the other direction. At 0.30
   the yaw error the robot actually made — 1.5 rad/s, flat across 3000 iterations of
   `walk_m3100_a` and `_b` — paid `1.4e-11`. Not a small reward, a **dead** one: no
   gradient, so the policy was never told to stop spinning. Raising the weight does
   nothing; twice zero is zero.
3. **MOVING = 0.05, not mjlab's 0.5.** Four terms gate themselves off below a command
   threshold, and Go1's 0.5 is above anything Gray is ever commanded. On the defaults the
   term that pays for picking a foot up is dead for the entire run.

**The generalisation, which is the actually useful part:** a tracking band has to be set
against the error the robot *makes*, not only against the command it is *given*. Both
numbers above were wrong for the same reason, in opposite directions.

---

## 3. Reference values from the established implementations

For any term you are thinking of adding or re-weighting.

### Task tracking

| Term | Typical weight | Where |
|---|---|---|
| `track_linear_velocity` | mjlab **2.0**; legged_gym / Isaac Lab **1.0**; Isaac Go2 **1.5** | `mjlab.tasks.velocity.mdp.rewards.track_linear_velocity` |
| `track_angular_velocity` | mjlab **2.0**; legged_gym **0.5** | `...rewards.track_angular_velocity` |
| `feet_air_time` | mjlab **0.0 — shipped disabled on Go1**; legged_gym **1.0**; ANYmal-flat **2.0**; Isaac Lab **0.125** | `...rewards.feet_air_time` |
| Raibert foot placement | Walk-These-Ways raw **−10.0** | must write |
| Gait-phase / contact schedule | Walk-These-Ways raw **4.0** | must write — mjlab has **no** phase reward |

### Posture and stability

| Term | Typical weight | Where |
|---|---|---|
| `posture` | ours **1.5** (stand), std 0.35 | `mjlab.envs.mdp.rewards.posture` |
| `variable_posture` | mjlab **1.0**; Go1 std 0.05→0.3 hip/thigh, 0.1→0.6 calf | `...velocity.mdp.rewards.variable_posture` |
| `upright` | mjlab **1.0**, σ = √0.2 | `...velocity.mdp.rewards.upright` |
| `flat_orientation_l2` | ours **−2.0** (stand, "tilt") | `mjlab.envs.mdp.rewards.flat_orientation_l2` |
| `body_angular_velocity_penalty` | mjlab **0.0** (off); ANYmal **−6·dt** | `...velocity.mdp.rewards.body_angular_velocity_penalty` |

### Gait and foot quality

| Term | Typical weight | Where |
|---|---|---|
| `feet_clearance` | mjlab **−2.0**, target 0.1 m | `...velocity.mdp.rewards.feet_clearance` |
| `feet_swing_height` | mjlab **−0.25** | `...rewards.feet_swing_height` |
| `feet_slip` | mjlab **−0.1**; Walk-These-Ways **−0.04** | `...rewards.feet_slip` |
| `soft_landing` | mjlab **−1e-5** | `...rewards.soft_landing` |

mjlab's `feet_clearance` and `feet_swing_height` both require a `TerrainHeightSensor`.
On a flat floor, height above the environment origin is the same number, which is why
Gray rewrites both against the foot sites. **On rough terrain (stage 8) they must go back
to the real sensor.**

### Smoothness, effort, actuator protection

| Term | Typical weight | Where |
|---|---|---|
| `action_rate_l2` | **−0.01** is the cross-framework anchor. Walk-These-Ways −0.1 on PD-target delta. Mini Cheetah −2e-4. **We tried −1.5 and it broke fall-catching.** | `mjlab.envs.mdp.rewards.action_rate_l2` |
| `action_acc_l2` | Walk-These-Ways equivalent **−0.1** | `mjlab.envs.mdp.rewards.action_acc_l2` |
| `joint_acc_l2` | legged_gym / Isaac Lab **−2.5e-7** | `mjlab.envs.mdp.rewards.joint_acc_l2` |
| `joint_torques_l2` | ANYmal **−1e-5**; **A1 / Go2 −0.0002**; ours **−0.0002** | `mjlab.envs.mdp.rewards.joint_torques_l2` |
| `joint_vel_l2` | ours **−0.001** (stand only); legged_gym **0** | `mjlab.envs.mdp.rewards.joint_vel_l2` |
| `electrical_power_cost` | Minitaur equivalent 0.008; LoComposition **0.008** ramped | `mjlab.envs.mdp.rewards.electrical_power_cost` — **not in any Gray task. Audit finding 3.** |
| `joint_pos_limits` | mjlab **−1.0**; **A1 / Go2 −10.0**; ours **−5.0** | `mjlab.envs.mdp.rewards.joint_pos_limits` |
| `self_collision_cost` | Go1 rough **−0.1** each | `...velocity.mdp.rewards.self_collision_cost` |

`joint_torques_l2` reads `actuator_force` — the simulator's computed force from the
position-PD law, not a measured torque. That is the right choice here: Gray has no torque
sensing, so this is a training-time shaping term only.

---

## 4. Per stage

### 1 — Stand still (done)

10 terms. `height` 2.0 (std 0.03), `still` 1.0 (std 0.25), `posture` 1.5 (std 0.35),
`alive` 0.5, `tilt` −2.0, `fell_over` −20, `effort` −0.0002, `joint_speed` −0.001,
`twitching` −0.01, `end_stops` −1.0.

Two of these were arrived at independently and match the references exactly:
**−0.0002 torque is A1/Go2's own config value** (against ANYmal's −1e-5 — a light,
weak-servo robot needs ~20× the torque penalty of an ANYmal-class one), and **−0.01
action rate is the cross-framework default**.

### 2 — Take a push (done)

Adds `spinning` −0.05, `skidding` −2.0, `foot_lift` +0.3, `jitter` −0.01. Re-weights
`posture` → 0.6, `still` → 0.5, `joint_speed` → −0.0002, `end_stops` → −5.0,
`fell_over` → −40.

`end_stops` at −5.0 is a step toward A1/Go2's −10.0 rather than a jump to it: Gray's knee
has 86° of travel in total and the stance already sits about 3° past the stop, so there is
no slack to spend.

`jitter` — the **second** difference of the action — is the right way to buy smoothness,
and Kim et al. use exactly this pair (first *and* second difference of the PD target) as
their single smoothness reward. `push_v3` tried to get the same thing by scaling
`twitching` 150× instead and the robot stopped catching itself: action-rate taxes speed,
and catching a fall **is** a large fast movement.

### 3 — Lift one foot (skipped)

**No mainstream framework has this stage at all** — legged_gym, Isaac Lab and every paper
surveyed go straight from standing to velocity tracking. Skipped here on purpose too.

If it is ever built: `upright`, `ride_height`, `posture` on the three stance legs,
`skidding` on the stance feet only, and a written `foot_target` of the form
`exp(−‖foot_pos − target‖²/σ²)`. For the trunk, score
`exp(−‖displacement − expected_shift‖²/σ²)` rather than all motion — the bar wants a
deliberate shift onto the tripod, not stillness.

### 4 — Step in place (skipped)

The standard toolkit points the **wrong way** here. mjlab's foot terms are all gated off
below a command threshold, and legged_gym ships a `stand_still` reward whose whole purpose
is to punish joint motion at zero command. Every mainstream framework wants the robot
frozen when not commanded to move.

Doing it properly needs a gait-phase reward that runs **independent of the velocity
gate** — which does not exist in mjlab. Port the Walk-These-Ways contact schedule
(phase `t += f_gait·dt`, Gaussian-CDF desired contact, `kappa ≈ 0.07`) driven by a
stepping-frequency command.

**Note the accident.** Gray's `stepping` term currently *is* un-gated, so this stage
partly happens by mistake inside stage 5 — for the 15% of environments commanded to stand.
That is audit finding 2, and it is a bug rather than a feature.

### 5 — Walk (live)

Section 2 above is this stage. Nothing to add.

### 6 — Steer

Same set as stage 5. mjlab's `UniformVelocityCommandCfg` already has the knobs: enable
`heading_command` and let the heading controller generate the yaw command; the existing
`track_turn` scores it. No separate "go straight" penalty is needed beyond `veering` and
`wandering`, which already exist.

### 7 — Stand up (not written)

The references are the two ANYmal recovery papers. Orientation is weighted **highest**
("recovers upright ASAP"), plus joint position, joint acceleration ("smooth motions"),
contact impulse ("avoid violent motions"), slippage, self-collision, action difference and
torque.

Mapped onto what exists: `upright` 1.0–2.0, `ride_height` 2.0, `posture` 1.0–1.5,
`joint_shock` −2.5e-7, `skidding` −0.1 to −0.3, `effort` as stage 5, and
`self_collision_cost` **repointed at a ground-contact sensor** to penalise slamming the
trunk down — the direct analog of the papers' impulse term, and nothing else in mjlab
covers it.

Two procedural lessons both papers state outright: **randomise the starting pose broadly**
(they drop from ~0.5 m with random joint angles, not one fixed pose), and **ramp the
penalties in from near zero** — same fix as RMA, same failure otherwise.

This is the one stage that genuinely warrants its own reward function rather than another
layer on the chain, because it is a different task, not a different command.

### 8 — Rough terrain (not written)

mjlab's `unitree_go1_rough_env_cfg` is close to a complete reference: `upright` re-pointed
at the terrain normal via `terrain_sensor_names`, clearance measured against a per-foot
`TerrainHeightSensor` rather than world Z, three −0.1 contact penalties (self,
shank-ground, trunk-ground), `illegal_contact` and `out_of_terrain_bounds` terminations
replacing the orientation-based one, and the `terrain_levels_vel` curriculum.

Lee 2020's rough-terrain weights: linear velocity 0.05, angular 0.05, base motion 0.04,
foot clearance 0.01, body collision 0.02, smoothness 0.025, torque 2e-5 — clearance and
collision stay small relative to tracking even on rough ground.

LoComposition (2026) disagrees with the whole approach and is worth reading before this
stage is built: it finds air-time and contact-count priors **reduce** rough-terrain
traversability, and gets better results from velocity tracking plus a mechanical-power
penalty and nothing else.

---

## 5. Known failure modes

**Standing still scoring well.** Five independent mechanisms produce it. Our own history
records a reward where standing beat walking. IsaacLab #458: a Solo12 given ANYmal's
weights "preferred to stand still", and a maintainer's reason is that reused weights do
not transfer because the actuator models and rewards were tuned for those robots. RMA hit
it with a fixed-weight penalty set. A σ borrowed from a faster robot **mathematically**
pays ~78% of maximum for doing nothing. And van Marum et al. state the general version
outright: *"most reward terms will be greater when a policy stands still with both feet on
the ground, than when it steps in place."* The bias is structural, not a bug you fix once.

**A term that returns zero looks exactly like a term that is passing.** This project has
been bitten four separate times: `feet_air_time` dead behind a Go1 threshold, `track_turn`
saturated at 1.4e-11 for three runs, `_going_straight` false for every backward command,
`ground_covered` paying nothing for backward walking right now. None of these throw. None
look wrong on a curve. The countermeasure is to log every term's contribution and hunt for
the ones sitting at zero — see [REWARD_AUDIT.md](REWARD_AUDIT.md).

**Foot scuffing without a clearance term.** Rudin 2021, from their own runs: "artifacts in
the behavior, such as a dragging leg or unreasonably high or low base heights."

**Jitter without an action-rate penalty.** CAPS (ICRA 2021): oscillation causes "poor
control, high power consumption, and undue system wear"; their smoothness penalty cut real
quadrotor power ~80%.

**Action-rate set too high.** Our own `push_v3` at −1.5 is the sharpest evidence
available: the robot stopped being able to catch itself. RMA's naive full-strength penalty
vector caused outright paralysis. **Fix is the ramp, not a lower constant.**

**Rushing the fall.** legged_gym clips the summed reward at ≥0 per step, its own comment
saying this "avoids early termination problems" — under net-negative reward a policy can
end the episode early rather than keep accruing penalty. **mjlab does not clip.** Gray is
currently net-positive throughout, but the two unbounded penalties ramp 10× and this is
the thing to watch.

**Too many terms to tune.** Kim et al.: "there are often more than ten reward terms" and
the tuning "often takes several months". Gray has 24.

**Simulating servos as stronger than they are.** D²-GMBC's own hardware result: rear
23 kgf·cm servos saturated during backward walking and degraded that gait direction by
**57.6%** — a failure the reward never saw because the sim did not model saturation.

**The structural finding.** Every project surveyed that actually ran RL on hobby servos
either escaped the actuator class (Stanford Pupper v3, Solo12, RealAnt all moved to
brushless or Dynamixel, citing no torque limiting and no overheat protection) or worked
around it (D²-GMBC, SpotMicroAI, rex-gym all use RL as a residual on a hand-written gait
generator rather than raw joint targets).

**Gray is in that class, not in the ANYmal/Go1 class mjlab's defaults were tuned against.**
Treat those numbers as a sound template but expect every effort, torque and action-rate
weight to need retuning by more than A1's already-20×-ANYmal adjustment, and expect the
biggest sim-to-real gap to appear as torque saturation on hard manoeuvres — fast turns,
catching a big shove, standing up — rather than as a training-time reward problem.

---

## 6. Sources

**Frameworks**: legged_gym (`legged_robot_config.py`, `a1_config.py`,
`anymal_c_rough_config.py`), Isaac Lab (`velocity_env_cfg.py`, `mdp/rewards.py`,
`go2/rough_env_cfg.py`), unitree_rl_gym, and the installed mjlab 1.5.3 source.

- Rudin et al., *Learning to Walk in Minutes*, [arXiv:2109.11978](https://arxiv.org/abs/2109.11978)
- Margolis & Agrawal, *Walk These Ways*, [arXiv:2212.03238](https://arxiv.org/abs/2212.03238)
- Margolis et al., *Rapid Locomotion via RL*, [arXiv:2205.02824](https://arxiv.org/abs/2205.02824)
- Hwangbo et al., *Learning agile and dynamic motor skills*, [arXiv:1901.08652](https://arxiv.org/abs/1901.08652)
- Lee et al., *Quadrupedal locomotion over challenging terrain*, [arXiv:2010.11251](https://arxiv.org/abs/2010.11251)
- Lee et al., *Robust Recovery Controller*, [arXiv:1901.07517](https://arxiv.org/abs/1901.07517)
- Kumar et al., *RMA: Rapid Motor Adaptation*, [arXiv:2107.04034](https://arxiv.org/abs/2107.04034)
- Rahme et al., *D²-GMBC*, [arXiv:2010.12070](https://arxiv.org/abs/2010.12070)
- Tan et al., *Sim-to-Real: Agile Locomotion*, [arXiv:1804.10332](https://arxiv.org/abs/1804.10332)
- Mysore et al., *CAPS*, [arXiv:2012.06644](https://arxiv.org/abs/2012.06644)
- Kim et al., *Not Only Rewards But Also Constraints*, [arXiv:2308.12517](https://arxiv.org/abs/2308.12517)
- van Marum et al., *Revisiting Reward Design and Evaluation for Robust Humanoid Standing and Walking*, [arXiv:2404.19173](https://arxiv.org/abs/2404.19173)
- *LoComposition: Terrain-Adaptive Energy-Efficient Quadruped Locomotion without Gait Priors*, [arXiv:2606.15896](https://arxiv.org/abs/2606.15896)
- *Learning-based legged locomotion: state of the art and future perspectives*, [arXiv:2406.01152](https://arxiv.org/abs/2406.01152)
- Chamorro, [legged-gym reward-term ablation](https://wandb.ai/simonchamorro/legged-gym/reports/Legged-Locomotion-Environment-Experiments-in-Isaac-Gym--VmlldzoxODE2MDY0)
- Voelcker, [Reward Design and Termination](https://cvoelcker.de/blog/2025/reward-functions/)
- [IsaacLab issue #458](https://github.com/isaac-sim/IsaacLab/issues/458) — standing-still reward hacking
- Solo12 clearance reward, [arXiv:2309.16683](https://arxiv.org/abs/2309.16683)

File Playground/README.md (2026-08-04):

# Playground

Somewhere to poke at a trained policy by hand. Nothing in here trains anything,
scores anything, or is read by the dashboard.

> **Not while something is training.** This opens a second process on the same
> graphics card, and there is no room for one — runs are sized to fill the card on
> purpose. Doing it once took the whole machine down and lost the run with it.
> Check the dashboard first: if anything is running, pause the queue and wait.
> RULES.md rule 4.

## Drive it yourself

```
Playground\pilot.bat                 the newest walk run
Playground\pilot.bat --run 25        a run by number, name, or folder
Playground\pilot.bat --run walk_v3 --checkpoint model_1500.pt
```

A window opens with one robot in it, and you steer it — with a **gamepad** if one
is plugged in, otherwise from the **numpad**.

## The gamepad

| control | does |
| --- | --- |
| left stick | walk: away from you is forward, sideways is a crab step |
| right stick | turn on the spot |
| `A` | stop |
| `B` | put it back on its feet |
| `ZL` held | drive it past the range it was trained on |

Full stick is the fastest speed it was ever trained on, so you cannot
accidentally ask for something meaningless. Push half way, walk half speed.

The pad is read on the physics thread, not through the window, so it keeps
working when the MuJoCo window is not the one in front.

If a stick does nothing or does the wrong thing:

```
Playground\pad.bat        prints every axis and button live, as you move them
```

The map it should match is at the top of `PadPilot` in
[pad.py](pad.py) — three axis names and three button numbers, measured on the
PowerA Switch pad. `Playground\pilot.bat --keys` ignores the pad entirely.

## The numpad

```
    7  crab left       8  faster         9  crab right
    4  turn left       5  STOP           6  turn right
                       2  slower
    0  straight ahead at the usual speed
```

| key | does |
| --- | --- |
| numpad `8` / `2` | forward, ±0.05 m/s per press |
| numpad `4` / `6` | turn on the spot, ±0.10 rad/s per press |
| numpad `7` / `9` | crab sideways, ±0.05 m/s per press |
| numpad `5` | stop — tell it to stand still |
| numpad `0` | straight ahead at the usual speed |
| mouse drag | move the camera |
| **ctrl + drag on the robot** | **shove it, and watch it catch itself** |
| space | pause |
| enter | put it back on its feet |
| `-` / `=` | slow motion / fast forward |
| `P` | show a live plot of every reward term |

**Why not WASD.** MuJoCo binds every letter from A to Z to one of its own view
toggles — `W` is wireframe, `S` is shadow, `A` is auto-connect, `D` is static
bodies, and so on for the whole alphabet. It handles them inside its C++ window
before Python sees the key, so they cannot be turned off: WASD steered the robot
and scrambled the picture at the same time. The numpad is the one block MuJoCo
leaves alone.

Speeds are **sticky**: a press changes the speed and it stays there until you
change it again, like a throttle. The window only reports keys going down, never
coming back up, so hold-to-walk is not available.

## What the readout means

Bottom left, while you drive:

```
told       +0.25 fwd   +0.00 side   +0.00 turn
doing      +0.21 fwd   +0.02 side   -0.04 turn
off line   +38 mm      heading -2 deg
falls      0           upright 0.98
```

- **told** — the three numbers you are sending. This is everything the policy
  knows about what you want.
- **doing** — what the trunk is really doing, smoothed over about half a stride.
  Raw, it is unreadable: every footfall makes the trunk surge at about four times
  its mean speed. This is smoothed exactly the way the walk reward smooths it, so
  it is the same number the policy was scored on.
- **off line** — how far sideways it has ended up from the line it was sent
  along, measured from where it was and which way it pointed when the straight
  command started. Resets when you ask for a turn: a turn is not drift.
- **heading** — how far it has rotated off that line. Different failure: a robot
  can hold a perfectly straight line while slowly turning to face sideways.
- **falls** — how many times it has gone over since the window opened.
- **upright** — 1.00 is level, 0.00 is on its side. Below 0.50 counts as fallen.

If **OUTSIDE WHAT IT TRAINED ON** appears, the command is outside the range the
policy ever saw. The walk policy trained on 0.15–0.35 m/s forward, ±0.10
sideways, ±0.5 rad/s turn. Ask for 0.9 m/s and it will fall over, and that tells
you nothing at all about the policy.

## What this is not

It shows how a policy **feels**. It does not show whether it **passes** — the eye
is easily fooled by a robot that looks busy. For that:

```
python scripts/verify.py Gray-Walk
python scripts/drive.py --run 25 --cases "0.25,0,0; 0.25,0.10,0"
```

If the *doing* line here and `drive.py` disagree for the same command, the
readout is wrong, not the policy.

## Files

| file | what it is |
| --- | --- |
| `pilot.py` | picks the run, builds the world, opens the window |
| `control.py` | the keyboard. Three floats — forward, sideways, turn |
| `pad.py` | the gamepad, read straight from Windows. Same three floats |
| `hud.py` | writes those floats into the policy's command, draws the readout |
| `pilot.bat` | launcher, because `.venv\Scripts\python.exe` is blocked here |
| `pad.bat` | the live pad probe |

`control.py` and `pad.py` know nothing about simulation on purpose — they hand
over three numbers and nothing else. The real robot takes the same three, so
whatever drives it later plugs in here without the rest changing.

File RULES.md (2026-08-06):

# Rules

Decisions that hold across the project, with the reasoning that produced them.
A rule goes here once, and everything follows it — rather than being re-argued
each time it comes up.

---

## 1. A run trains its full schedule. There is no early stop.

**The rule.** A run trains every iteration it was asked for. Nothing ends it
early except a person, a crash, or the queue runner being told to stop.

**What was here before, and why it is gone** (owner's call, 6 Aug 2026).
Training used to stop as soon as the mean reward reached 96.5% of the most an
episode could score — the sum of the positive weights times the episode length.
The argument was that at the ceiling every positive term is maxed, so the rest
of the schedule is polish. `--stop-at` was the dial, and it defaulted to on.

**The argument was wrong in one specific way: the reward is not what a run is
judged on.** Rule 2 says a stage is passed by its bar, not by its curve — and
the stop watched the curve. A walk policy sits at 96.5% of its ceiling while
drifting 5 degrees off its line and turning at three quarters of the rate it
was told, because those two faults cost a sliver of a total dominated by
staying upright and moving at all. The stop fired on a number nobody grades,
and ended runs that were still improving on the numbers everybody grades.

**It also made run lengths incomparable.** Two runs of the same config stopped
at different iterations, so a difference between them could be the change under
test or could be the 200 iterations one of them never trained. Every batch since
1.3 had to switch the stop off by hand to be readable at all, which is the sign
of a default pointing the wrong way.

**What replaces it.** Nothing automatic. Ask for the iterations you want; read
the curve afterwards; and if the numbers are still climbing at the end, continue
the run with `--init-from` rather than guessing longer next time. Continuing
costs only the extra iterations, so the choice of length is never final.

**The cost of this decision, stated plainly.** Runs that converge early now burn
card time to the end of their schedule. That is the price of never again asking
"did this run stop because it was finished, or because the reward flattened?"

---

## 2. A stage is passed by its bar, not by its curve

`scripts/verify.py` decides, over the full duration the bar names, across many
robots at once. The reward is a weighted sum that can read excellently while one
term quietly fails, and an episode is shorter than the bar — so a policy that
drifts after twenty seconds still shows a clean training curve.

---

## 3. Measure the machine, do not guess at it

How many robots fit on the card, how much torque a joint needs, how wide the
body is: all of these are measurable in minutes, and all of them have been wrong
when assumed. `scripts/probe_envs.py` answers the first, `scripts/find_stance.py`
the second, and both write down what they found.

---

## 4. One training process on the card at a time

**The rule.** Never start a second run — not even a three-iteration smoke test —
while another is training. Wait, or stop the first one.

**Why.** Runs are sized by `probe_envs.py` to fill the card on purpose: the push
task at 6400 robots holds 10.2 GB of 12.3 GB. There is no room for a second
process, and the failure is not a clean error. Both processes sit at 100% GPU
utilisation, allocating and stalling, and neither makes progress.

**What it looks like.** Exactly like a hung dashboard. The GPU is pinned, the fans
are loud, and nothing is being written — because nothing is happening. The monitor
is telling the truth; there is genuinely no new data.

**What the evidence looked like.** A 256-robot smoke test started at 01:47:22 on
top of push_v4. push_v4's last checkpoint was 01:47:13. Neither process advanced
for the next eighteen minutes. Killing the smoke test alone brought push_v4 back
within one checkpoint interval, unharmed — the deadlock costs time, not the run.

**In practice.** `nvidia-smi` before starting anything. If a python process is
already holding GPU memory, do not start a second one.

**This is not only about training runs.** Anything that opens a simulator counts,
because the card does not care what the second process is for:

- `Playground\pilot.bat` — driving a policy by hand
- `scripts/drive.py` — measuring what a policy does when told
- `scripts/find_stance.py --render` and the pose editor's render
- any viewer window at all

Opening the Playground viewer during a training run once took the whole machine
down and lost the run with it. The rule is the same rule: **one thing on the card,
and training wins**. Wait for the queue to drain, or pause it.

The dashboard itself is safe — it is CPU only. So is `find_stance.py` without
`--render`.

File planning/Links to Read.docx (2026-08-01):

https://github.com/open-dynamic-robot-initiative

https://www.science.org/doi/10.1126/scirobotics.abj7562

https://www.science.org/content/article/drone-has-legs-watch-flying-robot-perch-branches-catch-tennis-ball-midair

https://www.google.com/search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

https://shop.bostondynamics.com/spot-arm?cclcl=en_US

https://shop.bostondynamics.com/spot-cam-ptz?cclcl=en_US

https://forum.arduino.cc/t/quadruped-robot-dog/701883

https://github.com/mit-biomimetics/Cheetah-Software/blob/master/documentation/getting_started.md

https://github.com/chvmp/champ

https://www.google.com/search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

https://github.com/adham-elarabawy/open-quadruped

https://arxiv.org/pdf/1901.00697.pdf

https://blog.arduino.cc/2020/10/10/make-your-own-3d-printed-arduino-powered-quadruped-robot-for-under-60/

https://www.researchgate.net/publication/330132363_Design_Development_and_Experimental_Realization_of_a_Quadrupedal_Research_Platform_Stoch/figures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

https://gallery.autodesk.com/projects/120472/spotmini

https://hackaday.com/2020/10/23/the-adorable-robot-spot-now-in-affordable-form/

https://pupper.readthedocs.io/en/latest/

https://github.com/stanfordroboticsclub/StanfordQuadruped

https://great3d.com/stanford-pupper-robot-carbon-fiber-parts/

https://stanfordstudentrobotics.org/pupper

https://hackaday.com/2020/05/12/robotic-open-source-puppy-needs-a-home/

https://hackaday.com/tag/quadruped/

https://hackaday.io/project/171456-diy-hobby-servos-quadruped-robot

https://robotics.stackexchange.com/questions/18366/question-about-programming-approach-of-a-dog-like-quadruped-robot

https://www.halidyildirim.com/lotp-robotdog-prototype-2

https://ibrahimbisen.github.io/Sublinks/Projects.html

https://www.amazon.com/s?k=servo&ref=nb_sb_noss_2

https://www.halidyildirim.com/

https://www.youtube.com/channel/UCfY4QudfnPH8X3gaX6DbpPw/videos

https://www.reddit.com/r/arduino/comments/j9bt4d/hi_everyone_my_son_halid_is_working_on_a/

https://www.epfl.ch/labs/biorob/misc/archive/cheetah-2/

https://github.com/mikeferguson/smaldog

https://os.mbed.com/users/ms523/notebook/eric-overview/

http://coretechrobotics.blogspot.com/2014/10/a-simple-quadruped-robot.html?showComment=1414028538554

https://github.com/miguelasd688/4-legged-robot-model

https://www.youtube.com/watch?v=tLrRlXxM5Yw&ab_channel=MSCArt

https://grabcad.com/library/walking-quadruped-robot-diy-1

https://www.youtube.com/watch?v=DfBF26DaT-M&ab_channel=JamesBruton

https://www.youtube.com/watch?v=4MGZvcd0xxc&t=4s&ab_channel=JamesBruton

https://www.youtube.com/watch?v=jmgKQeorfZY&t=162s&ab_channel=JamesBruton

https://www.reddit.com/r/robotics/comments/qyzii8/the_quadruped_i_have_been_working_on_for_the_past/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

https://pytorch.org/

https://www.youtube.com/watch?v=2OjEeiT69ug&ab_channel=MATLAB

https://www.youtube.com/watch?v=6DL5M9b2j6I&ab_channel=MATLAB

https://www.youtube.com/results?search_query=how+to+teach+quadruped+walking+matlab

https://www.youtube.com/results?search_query=how+to+use+mit+app+inventor+with+arduino

https://www.amazon.com/Slamtec-RPLIDAR-Scanning-Avoidance-Navigation/dp/B07TJW5SXF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

https://arstechnica.com/gadgets/2020/06/boston-dynamics-robot-dog-can-be-yours-for-the-low-low-price-of-74500/

https://www.mathworks.com/videos/matlab-and-simulink-robotics-arena-walking-robots-pattern-generation-1546434170253.html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

https://github.com/mathworks-robotics

https://www.mathworks.com/matlabcentral/fileexchange/64227-matlab-and-simulink-robotics-arena-walking-robot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

https://www.mathworks.com/videos/deep-reinforcement-learning-for-walking-robots--1551449152203.html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

https://blogs.mathworks.com/student-lounge/2019/12/20/walking-robot-modeling-and-simulation/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

https://www.mathworks.com/videos/modeling-and-simulation-of-walking-robots-1576560207573.html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

https://www.mathworks.com/matlabcentral/answers/251947-basic-things-for-creating-a-simulated-robot-walk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

https://www.mathworks.com/help/deeplearning/ug/train-biped-robot-to-walk-using-reinforcement-learning-agents.html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

https://www.mathworks.com/help/reinforcement-learning/ug/train-biped-robot-to-walk-using-reinforcement-learning-agents.html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

https://www.mathworks.com/videos/reinforcement-learning-part-4-the-walking-robot-problem-1557482052319.html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

https://www.mathworks.com/videos/matlab-and-simulink-robotics-arena-walking-robots-part-3-trajectory-optimization-1506440520726.html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

https://www.mathworks.com/search.html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

https://www.youtube.com/watch?v=6qbW7Ki9NUc&ab_channel=sentdex

https://www.youtube.com/watch?v=Wypc1a-1ZYA&ab_channel=MATLAB

I need to do matlab

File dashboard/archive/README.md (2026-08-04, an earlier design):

# The eight-page dashboard, archived 3 Aug 2026

Kept because these files are where the current six pages came from, and because a
diff against them is the only record of what moved where. Nothing serves them:
`server.py` resolves a URL to `dashboard/<name>.html`, and this is a subdirectory,
so `/stage2` is now a 404 rather than a page from before the rebuild.

## What replaced what

| archived | now | what happened |
|---|---|---|
| `overview.html` | `control.html` | kept the log-scale bar track, the three-number rule and the blocked-rows grouping. Gained the queue and job-log tabs. Lost its own run table - `/runs` has that, built better. |
| `monitor.html` | `runs.html` | every chart, tab and live-refresh mechanism carried over byte-for-byte. Lost 209 lines of its own CSS and its duplicated helpers. Gained a nav bar; it had none. |
| `index.html` | `summary.html` | content unchanged. Its six diagrams kept their private CSS, rewritten onto the shared tokens. Lost the "Pages" section, which the nav does now. |
| `pose.html` | `robot.html`, Pose tab | behaviour identical - same dials, same endpoints, same travel editor. Gained a nav bar, replacing a `← Monitor` link that pointed at a page which had stopped being the monitor. |
| `stage1.html` | `robot.html`, Model tab | every panel kept. |
| `stage3.html` | `robot.html`, Hardware tab | every panel kept. |
| `stage2.html` | `train.html` | kept whole. Renumbered to PLAN.md and the by-category table swapped for the collapse table, because the library it reads went from 200 rows to 60. |

`plan.html` is not here. It was rewritten in place, from the A-F phase structure
to PLAN.md's five steps.

## Why there were eight and now six

Not the count. The overlap:

- the **run table** was on two pages, rendered by two different bits of code
- the **plan** was on four pages, and they showed four *different* plans
- `/index` and `/index.html` served two different pages
- the pose editor had no way back to anything

And two stylesheets that both defined `--line`, `--ink`, `--warn` and `--accent`
with **different values**, so a component copied between pages silently changed
shade, and the same criterion printed as `2125.0`, `2125` and `2125.00` depending
on which page you were looking at.

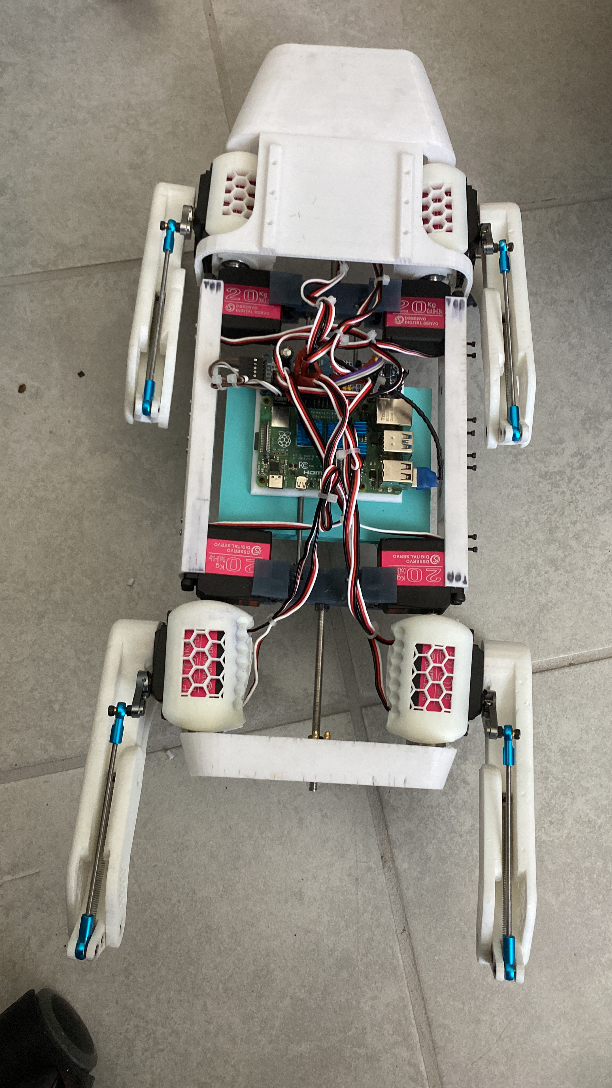
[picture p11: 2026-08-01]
Overview/D50167F7-8F12-43D7-A90E-EBB300F50C6A.JPG

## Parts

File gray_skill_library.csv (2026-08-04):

id | name | kind | group | coverage | blocked_on | dial | note | covers
1 | Hold a commanded ride height | run | R1 | blocked | height | 50 to 100 % of nominal height | Sit, stand, crouch, sneak, squeeze under, crawl and rear up are all one number the command vector does not have. | 1 2 3 4 5 14 34 35 90 167 170 171
2 | Pitch, roll and yaw the body with the feet planted | run | R1 | blocked | height | +/- 25 deg | Bowing, stretching, shaking, leaning and scanning are attitude commands rather than rates; old row 6 gave +/- 20 deg and old row 7 gave +/- 25 deg, so the dial is widened to cover both. | 6 7 168 172 173 174 175
3 | Address one leg on its own | run | R1 | blocked | foot |  | A three-legged stance, a diagonal pair or one leg held out needs a per-foot command, and nothing in vx, vy, yaw addresses one leg. | 8 9 10
4 | Lift a foot and hold it up | run | R1 | emerges |  | 0 to 10 s | Feet come off the ground because the gait reward makes them, not because anyone asks. | 17 18 20
5 | Turn in place | run | R1 | command |  | 45 / 90 / 180 / 360 deg | Slow, fast, and stopping on an exact angle are the same yaw command. | 11 12 13
6 | Turn where the ground or the space is against it | run | R1 | command |  | 0.1 to 0.3 friction | Turning on ice or in a gap 1.1 times the body length is the same command with the world turned up. | 15 16
7 | Walk forward at a commanded speed | run | R1 | command |  | 0 to 0.35 m/s | Stepping in place is this command at zero and holding the line for 3 m is R1's existing drift bar, so idle sway at zero command is not a separate skill. | 24 25 129 176
8 | Walk backward, sideways and diagonally - the whole command box | run | R1 | blocked | range | -0.35 to 0.35 m/s | Measured on run 25: backward walked 0.00 m in 8 s and pure sideways 3 cm, because WALK_SPEED is 0.15 to 0.35 and vx is never zero or negative. | 26 27 28 30
9 | Start, stop and reverse hard | run | R1 | command |  | 90 / 180 deg | Instant start, a dead stop from a sprint and a 180 at full speed are step changes in the same command. | 31 32 33
10 | Walk a constant arc | run | R1 | command |  | 0.3 to 2 m radius | A constant speed plus a constant turn rate is a circle, a figure eight is two of them flown back to back and turning at speed is the same pair held at 80 % of top, so the radius dial is widened to span every old row. | 29 156 193 194
11 | Named gaits | run | R1 | command |  |  | Static crawl, pace, amble and backward trot are contact patterns the gait reward already shapes; the gaits with a flight phase are parked. | 159 160 161 165
12 | Switch gait mid-walk | run | R1 | command |  |  | Changing gait is a speed change, not a new policy. | 36
13 | Step on command, one step at a time | run | R1 | command |  | 0.5 to 2 Hz | One step per command, at a commanded rhythm. | 19 166
14 | Step over a low object | run | R1 | emerges |  | 5 to 50 mm | A rug edge, a cable or a 40 mm block is felt through the leg on contact rather than seen, which is why old row 99 filing the same event as blocked on a camera was wrong; PLAN 5.2 notes range finders reach the anticipating half of it, and the dial spans all three old ranges. | 22 37 99
15 | Place a foot on a chosen spot | run | R1 | blocked | camera | 30 to 60 mm target | Hitting a mark, a stepping stone or the next stair but one needs to see where the spot is, and range finders give range, not a foot-placement map. | 21 130 199
16 | Probe the ground before committing weight | run | R1 | emerges |  |  | Tapping and scraping before loading a foot fall out of the contact rewards. | 178 179
17 | Pivot, cross over, and brace on a wall | run | R1 | emerges |  | 0 to 90 deg | A wall is felt through the leg when it pushes against it, the same way a low obstacle already is. | 185 186 196
18 | Reverse out of a tight place | run | R1 | pilot |  |  | Backing out of a corner, a dead end or a 50 mm gap is what a human on the sticks is for. | 91 128 195
19 | Drive to a point and stop on a heading | run | R1 | pilot |  | 0.5 to 3 m | The pilot decides where the point is, which heading to stop on, and how to line up on a doorway. | 126 127 131
20 | Descend a steep slope | run | R1 | condition |  | 20 to 45 deg | A steep slope is terrain, a dial in the scene, and going down it backward is just a command. | 197 198
21 | Get up from any ground pose | run | R2 | command |  |  | Belly, either side, fully upside down and rolling through the side are one reward with one fixed goal - get upright. | 72 73 74 169
22 | Get up on a slope or in a tight space | run | R2 | command |  | 10 / 20 deg | The same reward with the floor tilted or the ceiling at 1.2 times body height. | 75 76
23 | Power on in an unknown pose | run | R2 | command |  |  | Powering on in a random joint pose, upside down, mid-air or with a foot trapped all land in R2's start distribution. | 116 117 118 119
24 | Picked up and set down elsewhere | run | R2 | command |  |  | Being set down is felt through the IMU and lands in an unknown pose, so it is a getting-up start and needs no eyes. | 107 137
25 | Survive a drop | run | R2 | command |  | 0.3 to 1.0 m | Four old rows each named one drop height; the height is a dial, not four skills. | 77 78 79 80
26 | Land badly | run | R2 | command |  | 0 to 45 deg off level | Landing on blocks or a slope, or already rotating, is the same drop with the start state turned up. | 81 82
27 | Recover from a slip, or choose to fall safely | run | R2 | command |  |  | A foot sliding out mid-walk and an unrecoverable state are the two ends of the same reward. | 83 84
28 | Use a foot on an object | parked | R3 | emerges |  | 0 to 1 kg | Pushing, dragging, pressing, kicking, digging and pawing all score the object rather than the robot, and PLAN.md shelves this with no trigger to un-shelve. | 23 180 181 182 183 184
29 | Push while standing | axis | D1 | condition |  | 0.15 to 0.4 m/s | Light, hard and hardest are the same impulse with the number raised, from any direction and contact point. | 39 40 41 42
30 | Push while walking | axis | D1 | condition |  | 0.15 to 0.4 m/s | The same shove, delivered while the feet are moving. | 43
31 | Sustained lean or a long push | axis | D1 | condition |  | 10 to 30 % body weight | A lean held for 10 s and a push held for 30 s are one sustained force. | 44 148
32 | A sharp tug or a kicked leg | axis | D1 | condition |  |  | A tether yank and a sideways impulse into the swing leg are sharp, not sustained. | 45 46
33 | Low friction underfoot | axis | D1 | condition |  | 0.05 to 1.0 | Ice, wet tile, a puddle, worn feet and the ground yanked away are one number, and friction 0.4 is already inside the 0.4 to 1.2 band randomised on every attempt today. | 47 55 98 141
34 | Grass, gravel and rubble | axis | D1 | condition |  |  | The policy never sees the word gravel, it sees the same numbers arriving in a different pattern. | 50 51 54
35 | Ground the foot sinks into | axis | D1 | condition |  | 0 to 20 mm sink | Sand and mud differ from gravel by letting the foot go down before it stops. | 52
36 | Uneven ground - blocks, gaps, a beam, a rug edge | axis | D1 | condition |  | 10 / 20 / 30 mm | Flat hard floor is the baseline everything else is measured against rather than a skill, and the rest of these are one roughness dial. | 48 49 53 57 58
37 | A surface that moves under it | axis | D1 | condition |  | 10 to 15 deg tilt | A treadmill is a test rig rather than a skill, and a see-saw and a loose plank are the same tilt dial. | 38 56 144
38 | Step into an unseen hole | axis | D1 | emerges |  | 0 to 50 mm deep | An unseen hole is exactly that - felt, not seen. | 59
39 | Slopes, up, down and across | axis | D1 | condition |  | 10 / 20 / 30 deg | Up, down and cross-slope are one terrain dial. | 63 64 65
40 | A curb or single tall step | axis | D1 | condition |  | 0 to 1 x leg length | A curb is the stair dial with one step in it. | 60
41 | Stairs, up and down | axis | D1 | condition |  | 0 to 175 mm rise | Human stairs at a standard rise, forward or backward. | 61 62 145
42 | Stairs with a load or a dead servo | axis | D1 | condition |  | +1 / +2 kg | Stairs are the hard case for every other dial, so the load and the dead servo get a row on top of it. | 66 149
43 | Payload | axis | D1 | condition |  | +/- 2 kg | Centred, off-centre to 50 mm, sloshing or changing mid-walk, it is one mass dial. | 67 68 69 70 71
44 | Weak, dead or under-powered servos | axis | D1 | condition |  | 30 to 80 % torque | One weak, two weak, one dead per joint in turn, or a flat battery are all reduced torque. | 92 93 94 97
45 | Get up under load or on bad ground | axis | D1 | condition |  | 0 to 20 deg | Getting up on gravel or a slope carrying 2 kg is R2 with D1's dials turned up, not a new skill. | 146 147
46 | Foot wedged or legs tangled | axis | D1 | condition |  |  | Wedged, tangled or standing on its own foot is a scene condition the policy has to survive. | 120 123 124
47 | Walled in, or walking into a wall | axis | D1 | condition |  |  | Chair legs and a wall are the same condition seen from outside. | 121 122
48 | Handled, tugged and blown sideways | axis | D1 | condition |  | 0 to 20 % body weight | A leash tug, a hand on the back and a gust are all sideways force. | 108 139 140
49 | Trip at speed, or anything else mid-walk | axis | D1 | condition |  |  | Anything carries no information and mostly it is a shove, and tripping at speed is a disturbance rather than a speed measurement. | 106 158
50 | Sensor noise, drift and command delay | constraint | C1 | condition |  | 20 / 50 / 100 ms | IMU bias to 2 deg, noise to 3x nominal and up to 100 ms of lag are simulator honesty, not damage. | 95 96
51 | An impossible order | constraint | C1 | condition |  |  | How it behaves when asked for a blocked path or an unreachable pose is a property of every run, not a run. | 125
52 | Quiet running and a power-save lock | constraint | C1 | condition |  |  | Quiet is a penalty on effort rather than something measured afterwards, and power-save is a state rather than a movement. | 134 177
53 | Startup joint sweep | constraint | C1 | measured |  |  | Every joint driven through its full range before anything else runs. | 200
54 | Fall, get up, keep walking | test | T1 | measured |  |  | PLAN step 3's handover test - R2 stands it up, hands over, R1 walks 5 m, 100 times with no stall and no fall-loop. | 109
55 | Chain moves without stopping | test | T1 | measured |  | 0 to 5 s hold | Sprint-stop-turn-sprint, stairs to flat to stairs, a friction change mid-stride, a freeze and resume, and an emergency stop are read off, never trained. | 111 112 113 114 115
56 | Top speed and the speed ladder | test | T2 | measured |  | 25 / 50 / 75 / 100 % of top | Raise the command until it fails and write down where, per surface, per direction and per payload. | 150 151 154 155 157
57 | Acceleration and a sustained run | test | T2 | measured |  | 60 s to 10 min | Zero to top speed, then hold 80 % of it, then keep walking for ten minutes. | 133 152 153
58 | Smoothness, read off the trained policy | test | T2 | measured |  | 20 to 100 % battery | Efficient gait at each speed, the same quality on a flat battery, and keeping an object on its back are numbers read off a policy rather than trained toward. | 132 135 136
59 | Jumping | parked | P1 | blocked | flight |  | Every contact-gated reward term returns zero the moment all four feet leave the ground, so the airborne part needs its own reward and its own run; PLAN.md un-parks it when stage 3.3 measures real servo speed under load. | 85 86 87 88 89 110 162 163 164 187 188 189 190 191 192
60 | Seeing | parked | P2 | blocked | camera |  | A camera the policy itself reads, plus a depth-to-heightmap pipeline and the worst sim-to-real gap on the list; reacting to an obstacle is already covered blind, only anticipating one needs eyes. | 100 101 102 103 104 105 138 142 143

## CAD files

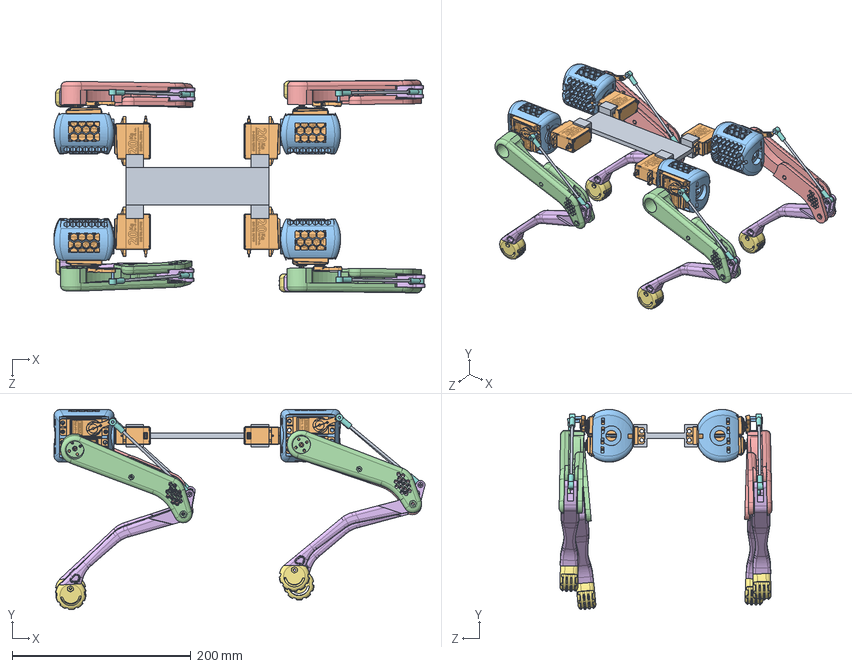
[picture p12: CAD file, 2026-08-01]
robot/Other/URDF File/Main_URDF_Assembly.SLDASM
415.1 x 224.0 x 238.1 mm
Main_Body
DS3218MG_MS24_Digital_Servo_270 x 12
HipJoint x 4
Left_Thigh x 2
Right_Thigh x 2
Leg_Universal x 4
Feet x 4
Ball_Bearing_End_Joint x 8
Long_Metal_Rod x 4
Servo_arm_25T x 4
Short_Metal_Rod x 4

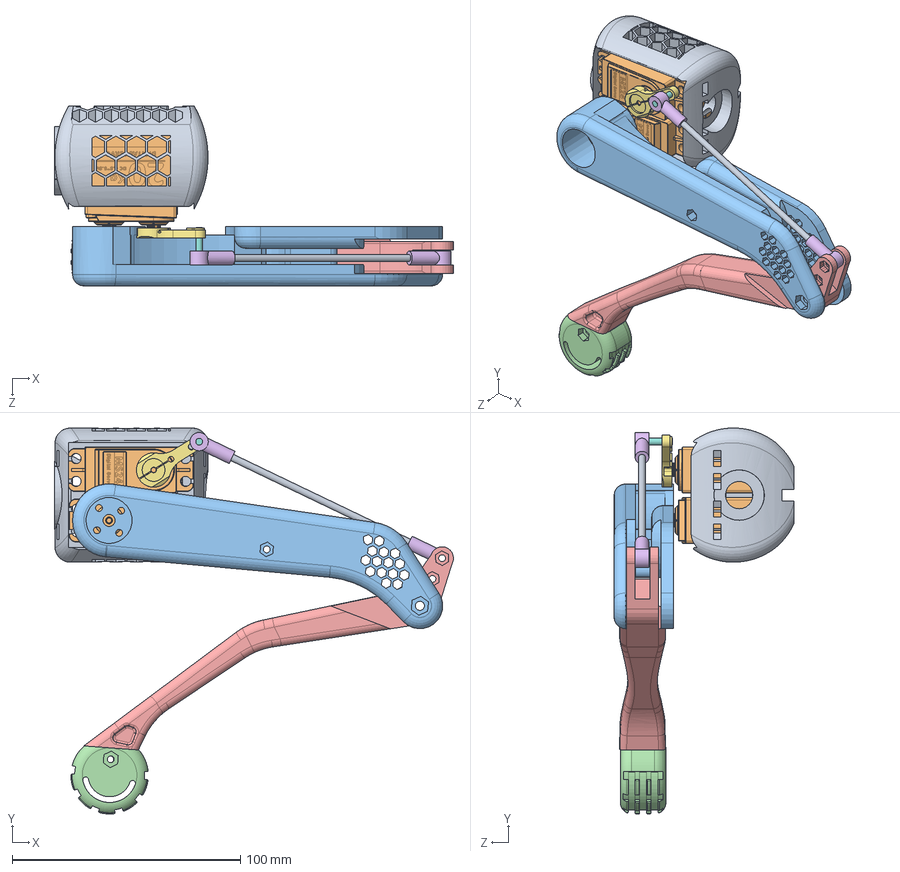
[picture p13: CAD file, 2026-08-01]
robot/Leg Parts/Extra/Back_Left_Leg_Assembly.SLDASM
174.7 x 169.0 x 78.8 mm
HipJoint
DS3218MG_MS24_Digital_Servo_270 x 2
Left_Thigh
Feet
Leg_Universal
Ball_Bearing_End_Joint x 2
Servo_arm_25T
Short_Metal_Rod
Long_Metal_Rod

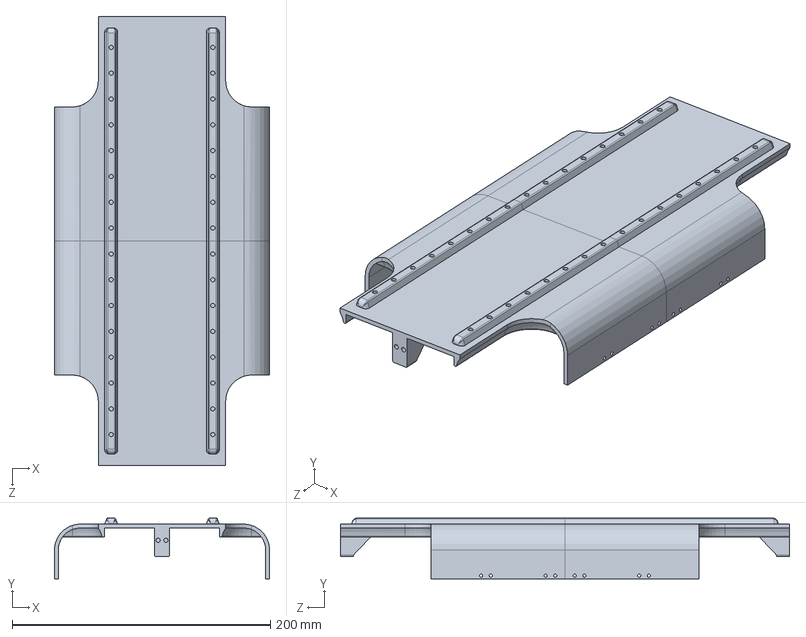
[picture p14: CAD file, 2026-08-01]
robot/Main Body Assembly/Full Cover.SLDASM
166.7 x 47.1 x 347.8 mm
Cover x 2

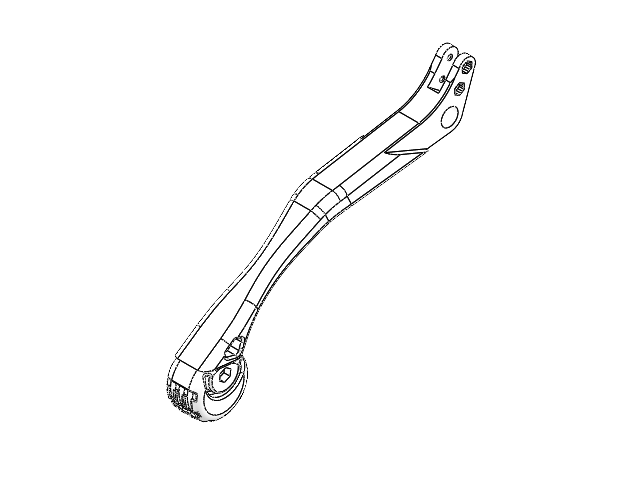
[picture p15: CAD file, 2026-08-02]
robot/Main Body Assembly/Assem3.SLDASM
Leg_Universal
Feet

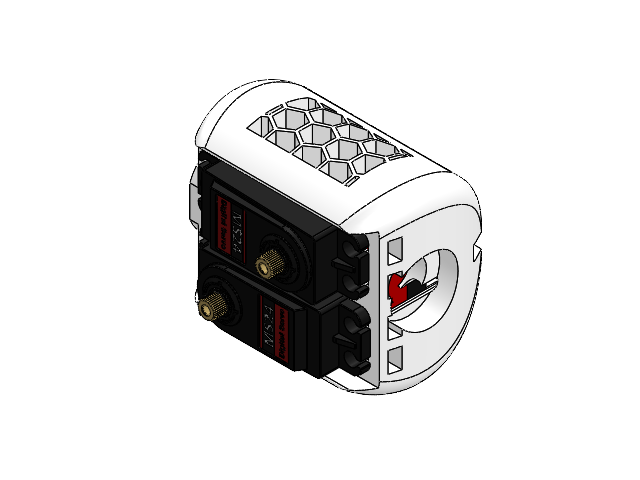
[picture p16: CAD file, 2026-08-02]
robot/Leg Parts/Back_Left_Leg_Assembly.SLDASM
HipJoint
DS3218MG_MS24_Digital_Servo_270 x 2

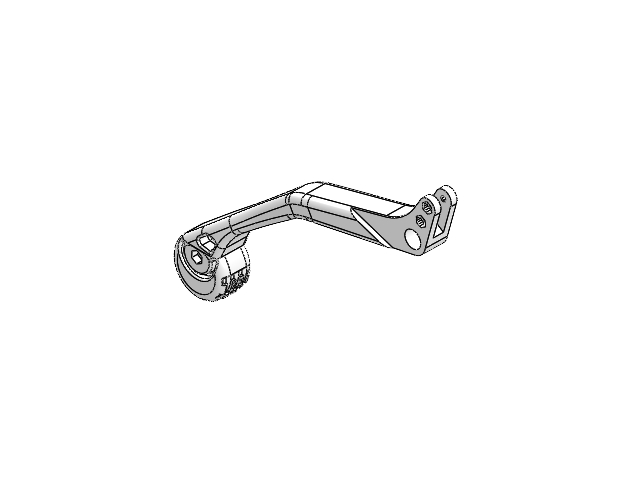
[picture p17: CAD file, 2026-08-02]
robot/Main Body Assembly/++Main_Assembly.SLDASM
Leg_Universal
Feet

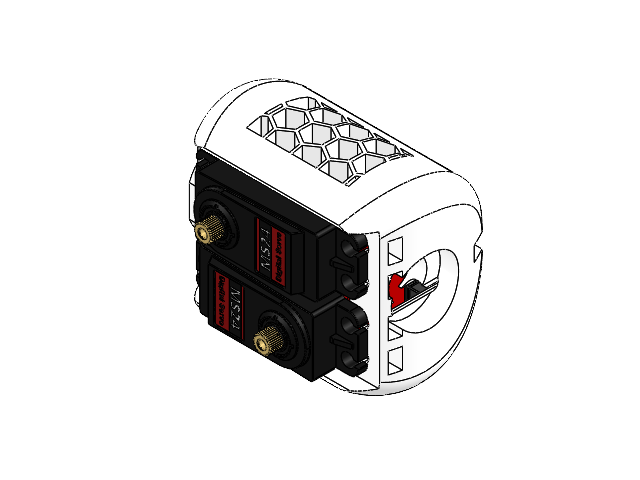
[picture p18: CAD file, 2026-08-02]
robot/Main Body Assembly/NEW URDF/right hip.SLDASM
HipJoint
DS3218MG_MS24_Digital_Servo_270 x 2

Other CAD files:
robot/Main Body Assembly/NEW URDF/Main Body Assembly.SLDPRT
robot/Main Body Assembly/URDF parts/Main Body Assembly - CENTER BALL BEARING_ME302_Reference-1.STL
robot/Other/Main_Body.SLDPRT
robot/Main Body Assembly/URDF parts/Main Body Assembly - Battery plate-1.STL
robot/Full Cover - Cover-1.STL
robot/Main Body Assembly/URDF parts/Main Body Assembly - Between_Motors-2.STL
robot/Main Body Assembly/URDF parts/Main Body Assembly - Head Plate-2.STL
robot/Main Body Assembly/URDF parts/Main Body Assembly - DS3218MG_MS24_Digital_Servo_270-4.STL
robot/Main Body Assembly/URDF parts/Main Body Assembly - Cover-3.STL
robot/Main Body Assembly/URDF parts/Main Body Assembly - Rody-1.STL
robot/Main Body Assembly/URDF parts/Main Body Assembly - Servo disc-2.STL
Sim/URDF and Meshes/meshes/base_link.STL
Sim/URDF and Meshes/meshes/calfbl.STL
Sim/URDF and Meshes/meshes/calfbr.STL
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

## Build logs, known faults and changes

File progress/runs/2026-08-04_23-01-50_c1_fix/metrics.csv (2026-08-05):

iteration | reward | episode_length | height_reward | upright_reward | tipped_over | collapsed | exploration | steps_per_second | speed_error | turn_error | stepping | leg_swing | dragging | ground_covered | landing_force | Curriculum/ease_in_effort/weight | Curriculum/ease_in_landing/weight | Curriculum/ease_in_shake/weight | Curriculum/ease_in_smoothness/weight | Curriculum/ease_in_steadiness/weight | Curriculum/ease_in_straightness/weight | Episode_Reward/alive | Episode_Reward/effort | Episode_Reward/end_stops | Episode_Reward/fell_over | Episode_Reward/hard_landing | Episode_Reward/jitter | Episode_Reward/joint_shock | Episode_Reward/landing_speed | Episode_Reward/posture | Episode_Reward/rocking | Episode_Reward/shaking | Episode_Reward/skidding | Episode_Reward/swing_height | Episode_Reward/track_speed | Episode_Reward/track_turn | Episode_Reward/twitching | Episode_Reward/veering | Episode_Reward/wandering | Episode_Termination/time_out | Metrics/posture/error_height | Metrics/posture/error_pitch | Metrics/posture/error_roll
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

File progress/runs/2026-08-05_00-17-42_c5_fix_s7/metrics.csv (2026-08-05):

iteration | reward | episode_length | height_reward | upright_reward | tipped_over | collapsed | exploration | steps_per_second | speed_error | turn_error | stepping | leg_swing | dragging | ground_covered | landing_force | Curriculum/ease_in_effort/weight | Curriculum/ease_in_landing/weight | Curriculum/ease_in_shake/weight | Curriculum/ease_in_smoothness/weight | Curriculum/ease_in_steadiness/weight | Curriculum/ease_in_straightness/weight | Episode_Reward/alive | Episode_Reward/effort | Episode_Reward/end_stops | Episode_Reward/fell_over | Episode_Reward/hard_landing | Episode_Reward/jitter | Episode_Reward/joint_shock | Episode_Reward/landing_speed | Episode_Reward/posture | Episode_Reward/rocking | Episode_Reward/shaking | Episode_Reward/skidding | Episode_Reward/swing_height | Episode_Reward/track_speed | Episode_Reward/track_turn | Episode_Reward/twitching | Episode_Reward/veering | Episode_Reward/wandering | Episode_Termination/time_out | Metrics/posture/error_height | Metrics/posture/error_pitch | Metrics/posture/error_roll
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

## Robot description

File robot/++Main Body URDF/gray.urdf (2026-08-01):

<?xml version="1.0" encoding="utf-8"?>
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
<robot name="Main Body URDF">
  <link name="base_link">
    <inertial>
      <origin xyz="-1.11022302462516E-16 -0.00302360042075001 -5.55111512312578E-17" rpy="0 0 0" />
      <mass value="0.315535261055246" />
      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
    </inertial>
    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
  </link>
  <link name="fl_hip">
    <inertial>
      <origin xyz="0.0272971333033659 1.75159621585708E-05 0.00247430441137858" rpy="0 0 0" />
      <mass value="0.0474176719706317" />
      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
    </inertial>
    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
  </link>
  <joint name="fl_hip" type="continuous">
    <origin xyz="0.0984 -0.0030292 -0.060681" rpy="0 0 0" />
    <parent link="base_link" />
    <child link="fl_hip" />
    <axis xyz="1 0 0" />
  </joint>
  <link name="fl_top">
    <inertial>
      <origin xyz="-0.0327093590748004 -0.0129114746104738 0.00626100034714228" rpy="0 0 0" />
      <mass value="0.139807399014711" />
      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
    </inertial>
    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
  </link>
  <joint name="fl_top" type="continuous">
    <origin xyz="0.0386 -0.011483 -0.032232" rpy="0 0 0" />
    <parent link="fl_hip" />
    <child link="fl_top" />
    <axis xyz="0 -0.01495 -0.99989" />
  </joint>
  <link name="fl_bottom">
    <inertial>
      <origin xyz="0.078482158861255 -0.0448672466577361 0.00348748963952544" rpy="0 0 0" />
      <mass value="0.0474313349742766" />
      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
    </inertial>
    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
  </link>
  <joint name="fl_bottom" type="continuous">
    <origin xyz="-0.12132 -0.072387 -0.013569" rpy="0 0 0" />
    <parent link="fl_top" />
    <child link="fl_bottom" />
    <axis xyz="0 -0.01495 -0.99989" />
  </joint>
  <link name="fr_hip">
    <inertial>
      <origin xyz="0.027297131982034 9.90275998717094E-05 -0.00247238563061042" rpy="0 0 0" />
      <mass value="0.0474176723475862" />
      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
    </inertial>
    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
  </link>
  <joint name="fr_hip" type="continuous">
    <origin xyz="0.0984 -0.0030292 0.060681" rpy="0 0 0" />
    <parent link="base_link" />
    <child link="fr_hip" />
    <axis xyz="1 0 0" />
  </joint>
  <link name="fr_top">
    <inertial>
      <origin xyz="-0.0327864495707164 -0.0126313769769459 -0.00647693886353867" rpy="0 0 0" />
      <mass value="0.139807219355074" />
      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
    </inertial>
    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
  </link>
  <joint name="fr_top" type="continuous">
    <origin xyz="0.0381 -0.012136 0.032026" rpy="0 0 0" />
    <parent link="fr_hip" />
    <child link="fr_top" />
    <axis xyz="0 -0.032164 0.99948" />
  </joint>
  <link name="fr_bottom">
    <inertial>
      <origin xyz="0.0791469661032436 -0.0433740165808617 -0.0042133669017476" rpy="0 0 0" />
      <mass value="0.047431300905697" />
      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
    </inertial>
    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
  </link>
  <joint name="fr_bottom" type="continuous">
    <origin xyz="-0.121749494844511 -0.0718844345331731 0.0123443050311544" rpy="0 0 0" />
    <parent link="fr_top" />
    <child link="fr_bottom" />
    <axis xyz="0 -0.0321638727308673 0.999482608798649" />
  </joint>
  <link name="br_hip">
    <inertial>
      <origin xyz="-0.0272971344226925 -6.43744326411511E-05 -0.00247351850938268" rpy="0 0 0" />
      <mass value="0.0474176686622597" />
      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
    </inertial>
    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
  </link>
  <joint name="br_hip" type="continuous">
    <origin xyz="-0.0984 -0.0030292 0.060681" rpy="0 0 0" />
    <parent link="base_link" />
    <child link="br_hip" />
    <axis xyz="-1 0 0" />
  </joint>
  <link name="br_top">
    <inertial>
      <origin xyz="-0.0331307458806611 -0.0121448427162066 -0.00584779936915039" rpy="0 0 0" />
      <mass value="0.139807219513831" />
      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
    </inertial>
    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
  </link>
  <joint name="br_top" type="continuous">
    <origin xyz="-0.0186000000001146 -0.0104099959720499 0.0325943550920316" rpy="0 0 0" />
    <parent link="br_hip" />
    <child link="br_top" />
    <axis xyz="0 0.0181540508072637 0.999835201640394" />
  </joint>
  <link name="br_bottom">
    <inertial>
      <origin xyz="0.0791720299116837 -0.043485483448343 -0.00202700123300074" rpy="0 0 0" />
      <mass value="0.0474313351974432" />
      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
    </inertial>
    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
  </link>
  <joint name="br_bottom" type="continuous">
    <origin xyz="-0.12368 -0.067775 0.015883" rpy="0 0 0" />
    <parent link="br_top" />
    <child link="br_bottom" />
    <axis xyz="0 0.018154 0.99984" />
  </joint>
  <link name="bl_hip">
    <inertial>
      <origin xyz="-0.0272971324067885 -3.03826091760384E-05 0.00247418544860611" rpy="0 0 0" />
      <mass value="0.0474176737292142" />
      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
    </inertial>
    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
  </link>
  <joint name="bl_hip" type="continuous">
    <origin xyz="-0.0984 -0.00302922105364486 -0.0606811932633948" rpy="0 0 0" />
    <parent link="base_link" />
    <child link="bl_hip" />
    <axis xyz="-1 0 0" />
  </joint>
  <link name="bl_top">
    <inertial>
      <origin xyz="-0.0332919917737501 -0.011761405740684 0.00583145711228239" rpy="0 0 0" />
      <mass value="0.139807399049" />
      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
    </inertial>
    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
  </link>
  <joint name="bl_top" type="continuous">
    <origin xyz="-0.0181000000001183 -0.0103448839199625 -0.0326150789771615" rpy="0 0 0" />
    <parent link="bl_hip" />
    <child link="bl_top" />
    <axis xyz="0 0.0201506967677564 -0.999796954096067" />
  </joint>
  <link name="bl_bottom">
    <inertial>
      <origin xyz="0.0817269974185858 -0.0387448949191614 0.00203600565191636" rpy="0 0 0" />
      <mass value="0.0474313022831092" />
      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
    </inertial>
    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
  </link>
  <joint name="bl_bottom" type="continuous">
    <origin xyz="-0.124595939429202 -0.0660533751871663 -0.0159842670738399" rpy="0 0 0" />
    <parent link="bl_top" />
    <child link="bl_bottom" />
    <axis xyz="0 0.0201506967677544 -0.999796954096068" />
  </joint>
</robot>

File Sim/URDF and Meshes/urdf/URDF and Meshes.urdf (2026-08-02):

<?xml version="1.0" encoding="utf-8"?>
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
<robot name="URDF and Meshes">
  <link name="base_link">
    <inertial>
      <origin xyz="0.71392 1.0029 1.438" rpy="0 0 0" />
      <mass value="0.8219" />
      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
    </inertial>
    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
  </link>
  <joint name="bl_hip" type="continuous">
    <origin xyz="0.65325 -1.2466 0.99369" rpy="1.6621 0 1.5708" />
    <parent link="base_link" />
    <child link="hipbl" />
    <axis xyz="1 0 0" />
  </joint>
  <link name="hipfr">
    <inertial>
      <origin xyz="0.032747 0.00029163 -0.0023623" rpy="0 0 0" />
      <mass value="0.096536" />
      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
    </inertial>
    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
  </link>
  <joint name="fr_hip" type="continuous">
    <origin xyz="0.65318 -1.5269 0.99379" rpy="-1.599 0 -1.5708" />
    <parent link="base_link" />
    <child link="hipfr" />
    <axis xyz="1 0 0" />
  </joint>
  <link name="thighfr">
    <inertial>
      <origin xyz="-0.0154492090074044 -0.00317139451254234 -0.0579467649483922" rpy="0 0 0" />
      <mass value="0.0755057669124192" />
      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
    </inertial>
    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
  </link>
  <joint name="fr_thigh" type="continuous">
    <origin xyz="0.0428999999999999 0.0133015103843757 -0.0298001110872436" rpy="-1.67995098611259 -1.51437912000812 -1.5707963267949" />
    <parent link="hipfr" />
    <child link="thighfr" />
    <axis xyz="1 0 0" />
  </joint>
  <link name="calffr">
    <inertial>
      <origin xyz="-0.014331 -0.031865 0.084376" rpy="0 0 0" />
      <mass value="0.046501" />
      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
    </inertial>
    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
  </link>
  <joint name="fr_calf" type="continuous">
    <origin xyz="0 -0.0229813332935709 -0.13928362829062" rpy="0.602256283932225 0 0" />
    <parent link="thighfr" />
    <child link="calffr" />
    <axis xyz="1 0 0" />
  </joint>
  <link name="hipfl">
    <inertial>
      <origin xyz="0.033166 -0.0079109 -0.12355" rpy="0 0 0" />
      <mass value="0.096535" />
      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
    </inertial>
    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
  </link>
  <joint name="fl_hip" type="continuous">
    <origin xyz="0.65318 -1.5269 0.99379" rpy="1.6337 0 -1.5708" />
    <parent link="base_link" />
    <child link="hipfl" />
    <axis xyz="1 0 0" />
  </joint>
  <link name="thighfl">
    <inertial>
      <origin xyz="0.0134586186491167 -0.00317135892094966 -0.0579467596966203" rpy="0 0 0" />
      <mass value="0.0755059396121985" />
      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
    </inertial>
    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
  </link>
  <joint name="fl_thigh" type="continuous">
    <origin xyz="0.0433999999999999 -0.0226201522727774 -0.152048058655485" rpy="-1.77915763399181 1.44502693130987 -1.57079632679489" />
    <parent link="hipfl" />
    <child link="thighfl" />
    <axis xyz="1 0 0" />
  </joint>
  <link name="calffl">
    <inertial>
      <origin xyz="0.0124727555104056 -0.0318645488514981 0.0843759664309658" rpy="0 0 0" />
      <mass value="0.0465012723740253" />
      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
    </inertial>
    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
  </link>
  <joint name="fl_calf" type="continuous">
    <origin xyz="0 -0.0229813332935703 -0.13928362829062" rpy="0.665062643185599 0 0" />
    <parent link="thighfl" />
    <child link="calffl" />
    <axis xyz="1 0 0" />
  </joint>
  <link name="hipbr">
    <inertial>
      <origin xyz="-0.034481 -0.0001582 0.0023734" rpy="0 0 0" />
      <mass value="0.096538" />
      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
    </inertial>
    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
  </link>
  <joint name="br_hip" type="continuous">
    <origin xyz="0.65325 -1.2466 0.99369" rpy="-1.737 0 1.5708" />
    <parent link="base_link" />
    <child link="hipbr" />
    <axis xyz="1 0 0" />
  </joint>
  <link name="thighbr">
    <inertial>
      <origin xyz="-0.034975626794023 -0.00317139627313623 -0.0579467657182859" rpy="0 0 0" />
      <mass value="0.0755057501906937" />
      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
    </inertial>
    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
  </link>
  <joint name="br_thigh" type="continuous">
    <origin xyz="-0.0443270345831046 0.0110000000000106 0.0109763134766172" rpy="2.5662721713198 1.5707963267949 0" />
    <parent link="hipbr" />
    <child link="thighbr" />
    <axis xyz="1 0 0" />
  </joint>
  <link name="calfbr">
    <inertial>
      <origin xyz="-0.0352711850014683 -0.0318645461200311 0.0843759701496383" rpy="0 0 0" />
      <mass value="0.0465012815456296" />
      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
    </inertial>
    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
  </link>
  <joint name="br_calf" type="continuous">
    <origin xyz="0.00141360721305017 -0.0229813332935683 -0.13928362829062" rpy="0.463611743275537 0 0" />
    <parent link="thighbr" />
    <child link="calfbr" />
    <axis xyz="1 0 0" />
  </joint>
  <link name="hipbl">
    <inertial>
      <origin xyz="0 0 0" rpy="0 0 0" />
      <mass value="0" />
      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
    </inertial>
    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
  </link>
  <joint name="bl_hip" type="continuous">
    <origin xyz="0.653247871299468 -1.24664584255998 0.993691155293609" rpy="1.66205952306395 0 1.5707963267949" />
    <parent link="base_link" />
    <child link="hipbl" />
    <axis xyz="1 0 0" />
  </joint>
  <link name="thighbl">
    <inertial>
      <origin xyz="0.174691001010413 0.00848228933157802 -0.0512582722591037" rpy="0 0 0" />
      <mass value="0.0755059373988258" />
      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
    </inertial>
    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
  </link>
  <joint name="bl_thigh" type="continuous">
    <origin xyz="-0.0443270345831046 -0.0134325586538961 -0.00781318280515964" rpy="2.54606361653767 -1.5707963267949 0" />
    <parent link="hipbl" />
    <child link="thighbl" />
    <axis xyz="1 0 0" />
  </joint>
  <link name="calfbl">
    <inertial>
      <origin xyz="0.0133686831492897 -0.0318645476416413 0.0843759715109755" rpy="0 0 0" />
      <mass value="0.046501282735256" />
      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
    </inertial>
    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
  </link>
  <joint name="bl_calf" type="continuous">
    <origin xyz="0.16033645351616 -0.0113276849352256 -0.132595140848383" rpy="0.555782608673983 0 0" />
    <parent link="thighbl" />
    <child link="calfbl" />
    <axis xyz="1 0 0" />
  </joint>
</robot>

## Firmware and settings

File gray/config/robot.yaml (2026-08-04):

# Gray - the numbers that describe the real robot.
#
# This file exists because the SolidWorks URDF exporter cannot be trusted with
# mass. It ignores a component's overridden mass and writes the part's volume in
# cm3 instead, which is the same as assuming everything is made of water. Every
# mass in a raw export is wrong by whatever the real density is.
#
# tools/prepare_model.py reads this and corrects the export.

mass:
  # Built up from known part weights, 3 Aug 2026. NOT scale readings - see
  # `measured: false`. Replace each line with a real number during reassembly.
  #
  # Why the CAD numbers were dropped. The exported meshes were measured against
  # the CAD masses and two separate faults showed up, pulling opposite ways:
  #
  #   part       mesh volume   CAD mass   implied density   separate shells
  #   thigh        73.91 cm3    75.51 g      1.022 g/cm3           1
  #   calf         46.36 cm3    47.43 g      1.023 g/cm3           3
  #   hip          96.47 cm3   172.07 g      1.784 g/cm3          85
  #   base_link   799.94 cm3  1198.66 g      1.498 g/cm3         551
  #
  # 1. Thigh and calf come out at almost exactly 1.0 g/cm3 - water. That is the
  #    SolidWorks exporter writing volume in cm3 into the mass field, so those
  #    two numbers are not masses at all.
  # 2. Hip and base_link are denser than water and split into 85 and 551 closed
  #    bodies, so those DO contain servos and fasteners as real geometry. But
  #    their printed plastic is still costed at solid density, and a part printed
  #    at 20-25% infill weighs roughly 45% of solid.
  #
  # WHERE THE SERVOS ARE - stated by the owner, 3 Aug 2026. Not inferred.
  #
  #   4 embedded in the body      - one per leg, these swing the hip out and in
  #   2 in each hip module (x4=8) - one drives the thigh, one drives the calf
  #   0 in the thigh              - it carries only the threaded pushrod and its
  #                                 ball joints, which run its full length
  #   0 in the calf
  #
  # So the calf is driven from the hip module through a rod that spans the whole
  # thigh. That is the pushrod linkage in CLAUDE.md, and it is why the calf can
  # be light while the hip is heavy.
  #
  # This split matters more than the total does. Two earlier versions of this
  # file got it wrong in opposite directions - one put a knee servo on each
  # thigh (legs came out 67% of the robot), one read the photos as 8 servos in
  # the body (42%). The truth is 55%. Leg mass is what a swing costs and what a
  # shove has to arrest, so a wrong split is worse than a wrong total.
  units: g
  measured: false
  # 1984 = 914 original + 840 net payload + 230 margin. See `payload_g` below.
  # Rounded UP to a 3100 g total on the owner's instruction: it is far easier to
  # shave mass off a model later than to discover the real robot is heavier than
  # everything was trained against. Being 200 g pessimistic costs a little
  # performance; being 200 g optimistic costs a retrain.
  trunk: 1984.0      # base_link, holds 4 of the 12 servos AND the whole payload
  hip: 165.0         # 4 off, TWO servos each - thigh drive and calf drive
  thigh: 65.0        # 4 off, no servo - printed arm plus a pushrod
  calf: 49.0         # 4 off, no servo
  total_expected: 3100.0

  # Every line above, itemised. These are the numbers to argue with.
  breakdown:
    plastic:
      material: PLA
      density_g_cm3: 1.24
      infill_pct: 22
      # Fraction of solid weight an FDM part actually comes out at, once
      # perimeters and solid top/bottom layers are counted. Infill alone would
      # say 0.22; perimeters dominate on parts this size.
      solid_fraction: 0.45
    known_parts_g:
      servo_ds3218mg: 60      # x12 = 720 g. Datasheet, and the single biggest item.
      raspberry_pi_4: 46
      pca9685: 10
      imu_mpu6050: 3          # x3 = 9 g, front / middle / back
      adc_ads1115: 5          # x3 = 15 g, 12 channels of pot
      pot_rotary: 8           # x8 = 64 g
      pot_linear: 15          # x4 = 60 g
      wiring_and_connectors: 120
      fasteners_bearings_pushrods: 140
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

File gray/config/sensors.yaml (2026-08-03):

# What Gray can be given to sense, and what each addition actually costs.
#
# Written 3 Aug 2026, after the owner's question: "we are adding cameras and
# sensors, so why is anything blocked?"
#
# ---------------------------------------------------------------------------
# THE RULE THAT ORDERS THIS WHOLE FILE
#
# A sensor is only useful to a trained policy if the SIMULATOR can produce a
# believable fake of it. The policy learns entirely in simulation. If the sim
# cannot generate the reading, the policy never sees it during training, and a
# reading it has never seen is noise on the real robot - worse than nothing,
# because it displaces a number that meant something.
#
# So every sensor here is judged on three separate costs, and they are not the
# same cost:
#
#   1. FIT IT      - money, mass, wiring, a board. Usually the smallest cost.
#   2. FAKE IT     - what the simulator has to compute, for every robot, every
#                    step, 4500 x 50 times a second. This is where a camera
#                    becomes expensive and a contact switch stays free.
#   3. TRUST IT    - how far the fake is from the real thing. A perfect
#                    simulated heightmap against a noisy 30 Hz depth camera
#                    full of holes is the hardest gap in the field.
#
# And one more, which applies to every row without exception:
#
#   4. ANY sensor added to the observation changes the length of the policy's
#      input list. That makes it a different policy. Every existing policy
#      file becomes unreadable and every run restarts from zero. So sensors
#      are added in BATCHES, at a deliberate moment - never one at a time.
#
# ---------------------------------------------------------------------------
# HONESTY NOTE ON PART NUMBERS
#
# Part numbers below are examples of the CLASS of device, chosen because they
# are common and cheap. Their specs are approximate and have NOT been checked
# against a datasheet. Confirm mass, current draw and update rate against the
# part actually bought. `spec_checked: false` marks every one of these.
# ---------------------------------------------------------------------------

# What the policy reads today. 45 numbers, and nothing else reaches it.
# Source: gray/tasks/stand_env_cfg.py, the "policy" observation group.
observation_now:
  total: 45
  terms:
    - {name: projected_gravity, n: 3,  from: IMU,
       note: "which way is down, in the trunk's own frame"}
    - {name: base_ang_vel,      n: 3,  from: IMU,
       note: "how fast the trunk is rotating"}
    - {name: joint_pos,         n: 12, from: potentiometers,
       note: "where each joint actually is"}
    - {name: joint_vel,         n: 12, from: potentiometers,
       note: "differentiated from joint_pos"}
    - {name: last_action,       n: 12, from: software,
       note: "the twelve targets it sent last step"}
    - {name: command,           n: 3,  from: operator,
       note: "forward, sideways, turn"}

# ---------------------------------------------------------------------------
# The sensors, ordered by value for what they cost. Best first.
#
#   status:   fitted | committed | candidate | not_recommended
#   unblocks: which BLOCKED_NEEDS keys in dashboard/skills.py this clears, and
#             roughly how many library rows that is. "-" means it unblocks no
#             library row but is still worth fitting, and says why.
# ---------------------------------------------------------------------------
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

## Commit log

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2026-08-02 Reset to CAD and photos, add CLAUDE.md
    Strip every line of the Phase 1-3 software. It was built on a SolidWorks
    export that is Y-up, carries no joint limits, and has servo geometry fused
    into link meshes, so the whole stack rested on guesses. It is preserved in
    the archive/attempt-1 tag.
    robot/ and Overview/ are untouched.
    [base_link.STL, bl_bottom.STL, bl_hip.STL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]
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2026-08-02 Environment, the CAD export validator, and the plan dashboard
    tools/check_urdf.py runs ten checks against a URDF and names the exact
    number that is wrong. Verified against the archived model: it reproduces
    the trunk-welding bug (902 g seen instead of 1625 g) and the exporter's
    default 270 deg joint limits.
    The dashboard explains what we are training for, what gets taught in what
    order, how points are given, and whether this machine can do it. Content
    lives in dashboard/plan.py as data; the HTML only renders it.
    [plan.py]
2026-08-02 Match the SolidWorks link names, and survive a blocked venv launcher
    Links are hipfr/thighfr/calffr, joints are fr_hip/fr_thigh/fr_calf, which is
    how the exporter is set up. Verified against the archived model renamed to
    the new scheme: 9/10, the one failure being the real MuJoCo trunk-weld bug.
    Windows Application Control started refusing to run .venv/Scripts/python.exe
    mid-session. run.py now falls back to the interpreter the venv was built
    from, with the venv's site-packages on the path. Also adds --check.
    [++Main_Assembly.SLDASM, Assem3.SLDASM, Back_Left_Leg_Assembly.SLDASM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]
2026-08-02 Catch duplicate joints, mirrored-away legs, and package:// mesh paths
    The first real export exposed three defects the checker was blind to: a
    joint defined twice so one link had two parents, both left hips sitting
    exactly on the right hips, and package:// URIs resolving against the wrong
    folder. All three are now checked.
    [Main Body Assembly.SLDPRT, URDF and Meshes.csv, URDF and Meshes.urdf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]
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2026-08-03 Correct the masses and give the robot a floating base
    The exporter writes each part's volume in cm3 as its mass - it ignores a
    component's overridden mass and assumes water. Confirmed by measuring the
    meshes: base_link 821.21 cm3 became 821.90 g, fr_hip 96.47 cm3 became
    96.54 g. Real masses now live in gray/config/robot.yaml and are applied
    after export, with each inertia tensor scaled by the same factor. Total
    lands on 2378.70 g, exactly what SolidWorks reports for the assembly.
    Also declares a floating base, without which MuJoCo welds base_link into
    the world and silently drops 1198.66 g of 2378.70 g.
    tools/make_mjcf.py converts to MJCF and drops the robot on a floor.
    10 of 11 checks pas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
    [robot.yaml]
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2026-08-03 Training monitor: runs, progress, checkpoint videos, and the plan
    The dashboard is now two pages. / is the monitor - what is training, how far
    in, the metric curves, a video of every checkpoint, and a card per run down
    the left with its purpose. /summary keeps the long version: the full
    curriculum and all fifteen scoring terms.
    dashboard/runs.py is the contract. Training writes exactly that layout and
    the dashboard reads exactly that layout, so neither side guesses. It imports
    neither torch nor MuJoCo, because the dashboard has to open when the training
    environment is broken - which is when you most need it.
    scripts/seed_demo_run.py writes one fake run, including video rendered from
    the re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
    [plan.py]
2026-08-03 Pose editor: drive the robot by hand and read the limits off it
    The travel currently in robot.yaml was stated from memory of a robot that is
    in pieces. Applied to this model it produces a robot standing on nearly
    straight legs at 308 mm, which is not how a quadruped stands, so the numbers
    need measuring against the geometry instead.
    /pose gives twelve dials, a live render, trunk height, stance width and a
    self-collision readout - a leg touching the body IS the mechanical limit, and
    this reports which two parts are touching. Type the angles in and save; they
    go back to robot.yaml.
    Zero is the sitting pose as exported, not something inferred from geometry.
    An earlier attempt derived a legs-s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
    [stance.yaml]
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2026-08-03 Detect a leg folding into its own thigh, and link the pages together
    MuJoCo never reported thigh-against-calf. It skips any parent-child pair
    outright, and where it does test meshes it tests their convex hulls, which on a
    bent leg are far too fat to mean anything. So collision is now done on the real
    triangles with FCL, which catches exactly the case that was missing:
    calf +30 br_calf into br_thigh by 19.0 mm
    Parts that already overlap at the sitting pose overlap by design - the knee
    pivot has the thigh and calf interleaved and they never separate - so a baseline
    is taken once and only new penetration counts.
    Two bugs found while building it. The mesh vertices were being read in the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
    [robot.yaml]
2026-08-03 Say what is actually on the floor, not just whether the toes are
    "Feet on the floor: 0/4" was true and useless. In the sitting pose the robot
    rests on the sides of its calves with its toes 14 mm in the air, and the tile
    only ever looked at the toe point.
    It now counts legs that reach the ground by any part, names the links that are
    touching, and lists every toe height alongside - so a pose that looks planted
    but is balancing on the wrong part of the leg is visible rather than hidden.
    sitting legs 4/4 toes 0/4 on: all four calves, toes 13.5-14.7 mm up
    calf -60 legs 4/4 toes 4/4 on: all four calves, toes 1.0-3.8 mm up
    [robot.yaml]
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2026-08-03 Measure how many robots the card can hold, instead of guessing
    8192 died at the first reset with "Warp CUDA error 600: device not ready" -
    MuJoCo-Warp captures the physics step into a CUDA graph, and when the card
    cannot hold it the failure looks nothing like running out of memory.
    scripts/probe_envs.py answers it directly. Each size runs in its own process,
    because a failed graph capture leaves the CUDA context unusable and everything
    after it in the same process fails too.
    robots result VRAM used left
    2,048 ok 6.06G 5.54G
    4,096 ok 11.59G 0.00G
    6,144 FAILED graph launch error
    4,096 is the ceiling at 11.59 GB of 12.88 GB. T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
    [metrics.csv]
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2026-08-03 Film checkpoints as training runs, so the robot can be watched learning
    mjlab's own recorder counts calls to env.step() rather than robot-steps, so the
    interval is easy to get wrong by a factor of num_envs - which is what happened:
    it filmed once, at step 0, and never again.
    scripts/film_checkpoints.py films from the saved checkpoints instead. Training
    saves one every 25 iterations regardless, so with --watch it runs alongside the
    run and each new checkpoint is filmed within half a minute of appearing. Films
    land straight in progress/runs/<run>/videos/ and show up on the dashboard.
    Three things it needed:
    - the simulator's state lives on the GPU, so it has to come back to the host
    be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
    [metrics.csv]
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2026-08-03 Wider stance, higher ride: feet outside the body instead of under it
    The robot stood on a base narrower than itself. Its hips are 121.4 mm apart and
    its trunk is 166.8 mm wide, so planting each foot straight under its hip put the
    whole support polygon 22.7 mm inside the body's own edge - easy to roll, and it
    looked wrong because it was.
    Feet are now planted 34 mm outboard of each hip, giving 189.4 mm of spacing and
    11.3 mm of margin outside the body. Ride height goes from 60% to 70% of full
    extension, 164.4 mm to 190.0 mm.
    The legs end up where they should: thigh swung back to -4.9 degrees instead of
    +6.4, knee bent to 43.7 instead of 30.8. Holding torque is unchanged at 3.57x
    the servo, a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
    [robot.yaml]
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2026-08-03 Stage 1 passed on the wide stance, and better than on the narrow one
    check narrow wide bar
    stayed up for 30 s 64/64 64/64 64
    trunk error, mean 1.21 mm 0.81 mm < 5
    trunk error, worst 2.30 mm 1.58 mm
    uprightness, worst 0.9996 0.9998 > 0.99
    Standing on a base wider than the body holds it steadier, which is what it looks
    like and now also what it measures. Neither policy fell in 64 robots x 30 s.
    Thirteen checkpoint films, iteration 0 to 599, filmed live this time rather than
    after the fact.
    [metrics.csv]
2026-08-03 Stage 2: take a push, and record the reasoning for doing it before walking
    The task is built on stage 1 rather than beside it - same stance, same rewards,
    same terminations - with a world added that will not hold still: a shove every
    two to four seconds from any direction, ground friction 0.4 to 1.2, mass +/-20%,
    servo gains +/-30%, gearbox drag, and the trunk's centre of mass moved +/-15 mm.
    Why here and not after walking, now written into the project summary: standing
    still can be solved without looking at anything, and nothing in the score would
    give that away. A shove cannot. It is the first task that genuinely uses the
    potentiometers, and walking needs the same reflex, since every step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
    [plan.py]
2026-08-03 One verifier for both stages, with each stage's own bar
    verify_stand.py becomes verify.py and takes a task, so the two stages share one
    gate rather than forking a second copy of the same measurement code - which is
    how the last attempt ended up with four rendering scripts and two evaluators.
    Stage 2's bar is deliberately not stage 1's. Being shoved every two to four
    seconds by an unknown amount, on unknown ground, with mass and gains varied, is
    not something to hold to a perfect score: nine in ten survive, 20 mm of height
    tolerance rather than 5, uprightness above 0.95 rather than 0.99. The robot is
    allowed to be knocked off its height, as long as it comes back.
    Steadiness is measured over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
    [metrics.csv]
2026-08-03 Fix the filmer following the wrong run, and size training to the card
    Two things were wrong and both were mine.
    The filmer had one task's log folder hardcoded, so while Gray-Push trained it sat
    watching the finished Gray-Stand run, printing "waiting for the next checkpoint"
    forever and filming nothing. It now asks the registry which task writes to which
    folder, follows whichever run is actually being written to, and rebuilds its
    environment if the task changes underneath it. It also sorts runs by their
    newest checkpoint rather than the folder timestamp, which stops moving while
    training is still writing into it.
    And the robot count was set from a probe of the wrong task. Gray-Stand tops ou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
    [metrics.csv]
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2026-08-03 Warn when a policy is being scored against a task that moved under it
    Scoring push_v2 came out at 76% survival against a 90% bar, which read as a
    failed stage. It was not. The run trained on 0.6 m/s box-shaped shoves and was
    being scored against 1.2 m/s ones from any angle - up to twice as hard, in a
    direction distribution it had never seen. The verifier silently answered a
    different question from the one it appeared to answer.
    verify.py now reads what the run was actually trained with, out of the env.yaml
    mjlab dumps at launch, and prints every difference before the verdict:
    WARNING - the task has changed since this run was trained:
    shove trained {'velocity_range': {'x': [-0.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
    [metrics.csv]
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2026-08-03 Reload the dashboard's data modules when they change on disk
    The server imported plan.py and runs.py once at startup, so every edit to a
    status rule or a reward description silently did nothing until somebody
    remembered to restart it - and the symptom looks exactly like a bug in the page.
    It cost a round trip here: two finished runs kept reporting "running" and the
    cards showed their title twice, both because the running server predated the
    change that fixed them.
    The modules are now reloaded when their file moves. The HTML was already re-read
    per request; this brings the data behind it into line.
    [metrics.csv]
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2026-08-03 Payload mass: 2030 g -> 3100 g, and mass bounds read from config
    The owner is fitting a Jetson Orin Nano dev kit, twelve 18650 cells in 3S4P,
    five cameras and about 200 g besides. None of it is in the CAD yet, so on the
    owner's instruction it goes onto the trunk as a single lump and gets
    distributed properly when the mounts are modelled.
    The arithmetic is not simply +1040 g: the 914 g trunk already carried a 200 g
    3S LiPo that the 18650 pack replaces. Net is +840 g, rounded up to a 3100 g
    total on the owner's call - it is far cheaper to shave mass off a model later
    than to find the real robot heavier than everything was trained against.
    What it costs: torque margin 4.18x -> 2.73x, still co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
    [robot.yaml]
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2026-08-03 A training queue, a runner to work it, and a dashboard to drive them
    Queue many runs, go to bed, wake up to filmed and scored results. Each job is
    train -> film -> verify, then the next one.
    dashboard/queue.py holds the queue in progress/queue.json. scripts/runner.py is
    a SEPARATE process - closing the dashboard must not kill a six-hour run. Start
    it with `python run.py --runner`, which shares the dashboard's interpreter fix.
    RULES.md rule 4 is now structural rather than remembered: next_queued() refuses
    to hand out a second job while one is running. Two runs on one card do not fail
    cleanly - both sit at 100% GPU and neither advances, which looks exactly like a
    hung dashboard.
    The card's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
    [metrics.csv]
2026-08-03 Fix the bugs two reviews found before they could ruin a night
    Every one of these was found by review, and the two worst were reproduced on
    this machine rather than argued about.
    CTRL_BREAK hard-killed the child. The runner stops a job by sending
    CTRL_BREAK_EVENT - the only signal that reaches a process in its own group on
    Windows - which raises SIGBREAK, and Python leaves SIGBREAK at its OS default:
    terminate immediately. Measured: exit 0xC000013A with both `except
    KeyboardInterrupt` and `finally` skipped. So train.py never wrote its final
    status and the run showed "running" for ever, which is the precise failure the
    design claimed to prevent. One signal.signal() line in train.py and
    film_c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
    [metrics.csv]
2026-08-03 Walk verification: test for 25 s, so the distance bar is reachable
    At the commanded 0.25 m/s, 20 s covers exactly 5.0 m. So "covered 5 m" could
    only be met by perfect speed tracking - quietly stricter than the "within
    0.05 m/s" check sitting next to it, and a robot at the slow edge of its own
    tolerance would fail a bar it had actually met.
    25 s means a robot holding 0.20 m/s, the slowest the speed bar allows, still
    makes the 5 m. The two checks now agree instead of one secretly overruling the
    other.
    Checked without touching the GPU: every attribute verify.py pins on the walk
    command exists and takes the value.
    [metrics.csv]
2026-08-03 A render check for the dashboard, so a blank page is not the first sign
    python run.py # in one terminal
    node tools/render_check.js
    Runs every panel builder from dashboard/monitor.html outside a browser, against
    the JSON the server is actually serving, plus an all-empty state. A JS error in
    a panel otherwise shows up as a blank page with nothing in any terminal to say
    which panel or why - and on a page that is meant to be left running overnight,
    that is discovered in the morning.
    Also flags "undefined", "[object Object]" and "NaN" appearing in rendered
    output, which is what a field-contract mismatch looks like before it becomes a
    crash.
    [metrics.csv]
2026-08-03 Two checks that catch a silently broken page, and the mass numbers on the plan
    tools/api_contract_check.py reads every `s.<field>` a page uses and checks it
    against the dict the server function actually returns. A shape change that
    leaves a page reading an old key renders a blank panel with nothing in any
    console - the one failure the dashboard is most prone to, because it is silent.
    It found real shadowing while being written: `s` means the page state in every
    one of these files, and compareChart had reused it for a series. Renamed to
    `ser`. The false positive was worth having.
    Also brings the plan's mass figures up to the payload: 3100 g, torque margin
    2.73x, and the leg fraction 55% ->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
    [metrics.csv]
2026-08-03 Fix seven defects the re-review found in the previous round of fixes
    Every one of these was introduced by the fixes themselves. The redraw gate in
    particular traded one bug for a class of new ones, which is what a re-review is
    for.
    The job log tab froze for ever once a log passed 40 KB. The server caps its
    reply at 40 000 chars and the signature keyed on JOBLOG_TEXT.length, so the
    length pinned there and the panel never redrew again - on the one tab whose
    entire purpose is watching output live, and only on the long runs worth
    watching. j0006.log is 817 KB. It keys on the tail now.
    Charts invented zeros. `+null` and `+""` are both 0, so a metric that starts
    logging at iteration 50 drew a fl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
    [metrics.csv]
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2026-08-03 Record the metrics that say whether it is walking, and stop shipping the lot
    Two WATCH entries pointed at tags nothing logs - Metrics/air_time_mean and
    Metrics/peak_height_mean - so they had been quietly doing nothing. Every tag
    here is now read off a real run's event file rather than guessed.
    Six added, all diagnostic rather than decorative. The reward is a weighted sum
    and can read excellently while the robot creeps on stiff legs scuffing its feet,
    which is exactly the gait that works in simulation and trips on carpet. Each of
    these isolates one way that happens: stepping (a gait or a shuffle), leg_swing
    (animated or not), dragging (scuffing), ground_covered (real progress or rocking
    in p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
    [metrics.csv]
2026-08-03 Measure walk drift against the heading it started on, not the world axis
    The first walk verification ran and worked - it produced a real verdict rather
    than an error - but its drift figure was unfair to the policy.
    reset() nudges the spawn yaw by up to +/-0.1 rad. A robot walking perfectly
    straight along its own nose from a 0.1 rad start shows 599 mm of world-frame
    lateral offset over 6 m, against a 100 mm bar. That is the test's own
    randomisation being charged to the policy, and it is invisible in the result.
    Displacement is now rotated into each robot's starting frame, so "forward" means
    the way it was pointing and "sideways" means off that line. Checked against
    hand-computed cases: a st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
    [metrics.csv]
2026-08-03 The turn reward was dead: TURN_STD 0.30 -> 0.80
    Two walk runs finished tonight. Both walked - over 5 m, 0 of 64 robots falling,
    on a robot 53% heavier than anything trained before - and both then drifted
    3.5-4 m sideways against a 100 mm bar. The second one, with leg_swing raised,
    drifted slightly worse. Neither improved on it at all over 3000 iterations.
    The new turn_error metric said why. It rose to 1.5 rad/s in the first 350
    iterations and sat there, flat, for the remaining 2650 - while speed_error
    improved steadily from 0.25 to 0.16. One tracking term was learning and the
    other was not moving at all.
    track_angular_velocity pays exp(-(yaw error squared + xy rotation) / std^2). At
    std =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
    [metrics.csv]
2026-08-03 Filming ceiling 3072 -> 3600 robots, on the owner's call
    What is known rather than assumed: 3072 with filming works, measured at 6.9 GB
    of 12.0 across several runs; 4096 with filming died 26 s in with CUDA error 600.
    3600 is between them and untested - a 17% step up from known-good rather than a
    jump to the known-bad number.
    The failure mode is fast and loud, so the cost of being wrong is a minute, not a
    night. If a run dies with error 600 again, FILMING_ENV_CEILING is the one line
    to put back.
    Applied to the queued jobs. The running one keeps 3072 - a job's settings are
    the record of what actually ran, so they are immutable once it starts.
    [metrics.csv]
2026-08-03 The 4096 crash was a race, not memory; and the model panel was lying
    Two separate things, both found by looking rather than assuming.
    THE CRASH. A stand run at 4096 robots with filming on died 26 s in, and this
    repo has said since that the video renderer had run the card out of memory. The
    owner measured it: 3072 uses 6.9 GB and 3600 uses 7.3 GB, so 4096 would have
    been about 7.8 GB of 12.0. Nowhere near.
    The traceback said the same thing all along. It failed in wp_cuda_graph_launch
    with CUDA error 600, cudaErrorNotReady - a graph LAUNCH failure. An allocation
    failure reports a memory error and looks nothing like it. And the timing was
    train.py at 05:56:52, film_checkpoints.py at 05:56:57,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
    [metrics.csv]
2026-08-03 An overview page: where the project stands against its bars
    Two agents designed this and agreed on the thing that matters: no percentages
    anywhere. Ten of twelve criteria met reads as "83% done" for a robot whose
    sideways drift is 24 times its bar, and that framing is exactly what a progress
    page is usually for.
    The blocker had to go first. verify.py measured six criteria, six bars and six
    verdicts and then flattened all of it into one prose sentence in run.json. It
    could be displayed and nothing else - not compared across runs, not charted, not
    turned into "how far off are we". It now writes the structure alongside the
    prose, which is kept byte-identical so older runs still render.
    New da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
    [metrics.csv]
2026-08-03 The overview becomes the front page, as a cockpit
    Owner's call: the dashboard should be its own thing, and the plan pages stay
    separate for reading and understanding. So / is now the overview, the run
    monitor moves to /runs, and /summary and /stage1-3 keep their own document
    layout untouched - they are for reading, not for flying.
    The overview no longer borrows page.css. It has its own instrument styling in
    the monitor's visual language: a rail of gauges across the top, a hero with the
    single worst number, then dense tables and sparklines down one scrolling screen
    with no tabs. Everything at once is the point.
    Every row that names a run is clickable and opens /runs#run=<id>, which now
    pres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
    [metrics.csv]
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2026-08-03 Film the whole walk, from far enough back to see it
    Two problems, both making the checkpoint films show almost nothing.
    The clip was 6 seconds. At 0.25 m/s that is 1.5 m of a walk whose bar asks for
    5 m, so every film ended a quarter of the way through and the interesting part -
    does it hold a line, does it still look like that at four metres - was never on
    screen. Now 20 s, which is exactly the 5 m the bar measures.
    The camera sat 1.0 m from the trunk and was locked dead on it. The robot filled
    the frame and stayed perfectly centred, so nothing on screen said whether it had
    covered five metres or none; the only cue was ground sliding past behind it.
    Now 2.6 m back and allowed to fall up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
    [metrics.csv]
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
